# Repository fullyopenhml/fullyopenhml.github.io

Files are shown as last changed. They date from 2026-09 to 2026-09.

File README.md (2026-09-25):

# Fully Open Humanoid

Three things in one site, at https://fullyopenhml.github.io/:

- **Catalog** (`catalog.html`): open-source humanoids, bipeds and hands scored on nine
  openness criteria, with cost, size, DOF, actuators, licences and sources.
- **Builder** (`builder.html`): mix legs, torso, arms, hands and head across projects;
  get a compatibility checklist (verified / unverified / adapter needed), a merged BOM
  with prices and a sourcing list.
- **Our reference design**: a 23-DOF, 1.1 m humanoid on RobStride actuators and
  3D-printed structure, keeping the joint layout of [Duke Humanoid V2](https://generalroboticslab.github.io/Duke_Humanoid_V2_OpenSource/)
  and the no-machining build of [Berkeley Humanoid Lite](https://berkeley-humanoid-lite.gitbook.io/docs).
  About $5.8k in parts, zero CNC parts, unbuilt.

## Layout

| Path | What |
| --- | --- |
| `index.html`, `design.html`, `viewer.html`, `bom.html`, `printing.html`, `assembly.html`, `electrical.html`, `bringup.html`, `software.html`, `reference.html` | The site: plain HTML, no build step |
| `catalog.html`, `builder.html`, `assets/js/builder.js` | The catalog and the mix-and-match builder, both rendered from `assets/data/catalog.json` |
| `tools/catalog_src.py` | **The catalog.** One dictionary per robot with sources, criteria, families, static modules; `tools/build_catalog.py` merges it with the computed modules of our design and Duke V2 |
| `tools/build_geometry.py` | Builds the builder's 3D modules: one decimated GLB per module in `assets/geom/` plus anchors in `assets/data/module_geom.json`, from our primitives, Duke V2's viewer GLB and the URDFs of BHL, LeRobot Humanoid, Open Duck Mini and MEVITA (meshes cached in `tools/.cache/`) |
| `assets/js/mix-viewer.js` | The builder's live 3D view (three.js), composes the selected modules by matching anchors |
| `tools/build_data.py` | **The model.** Every part, joint, price. Writes the three files below |
| `assets/data/robot.json` | Links, joints, part occurrences as primitive solids, catalogue, poses, specs |
| `assets/data/bom.json` | Bill of materials by section and tier |
| `assets/model/foh_v0_2.urdf` | Robot description with masses and inertias |
| `assets/print/` | One STL per printed part plus a zip; `assets/data/print_files.json` is the manifest |
| `tools/build_parts.py` | STL generator (CSG with manifold3d); `tools/check_collisions.py` is the self-collision audit |
| `assets/js/robot-viewer.js` | The CAD-style viewer (three.js from a CDN), builds the robot from `robot.json` |
| `assets/js/site.js`, `assets/css/site.css` | Shared behaviour and styles |
| `Duke_Humanoid_V2_OpenSource/`, `berkeley-humanoid-lite/` | The two parent projects, kept for reference |

## Working on it

```bash
python3 tools/build_data.py          # regenerate robot.json, bom.json and the URDF after any change
python3 tools/check_collisions.py --poses --sweep   # self-collision audit
python3 tools/build_catalog.py       # regenerate catalog.json after editing tools/catalog_src.py
uv pip install --python tools/.venv/bin/python open3d DracoPy pycollada
tools/.venv/bin/python tools/build_geometry.py     # regenerate the builder's module GLBs and anchors
uv venv tools/.venv --python 3.12 && uv pip install --python tools/.venv/bin/python manifold3d trimesh numpy
tools/.venv/bin/python tools/build_parts.py         # regenerate the STLs and the manifest
python3 -m http.server 8000          # then open http://localhost:8000/
```

Change a dimension, a part or a price in `tools/build_data.py`; every page, the
viewer and the URDF follow. Never edit the generated files by hand.

## Status

v0.2 is a design release: kinematics, part list, cost model, wiring, URDF and every printed part as STL.
Nothing has been built yet. The roadmap on the home page lists what each
version adds and which numbers turn from estimates into measurements.

## Licence

Code is MIT (`LICENSE`). Hardware design files and documentation are CC BY 4.0.
See the [reference page](https://fullyopenhml.github.io/reference.html#license).

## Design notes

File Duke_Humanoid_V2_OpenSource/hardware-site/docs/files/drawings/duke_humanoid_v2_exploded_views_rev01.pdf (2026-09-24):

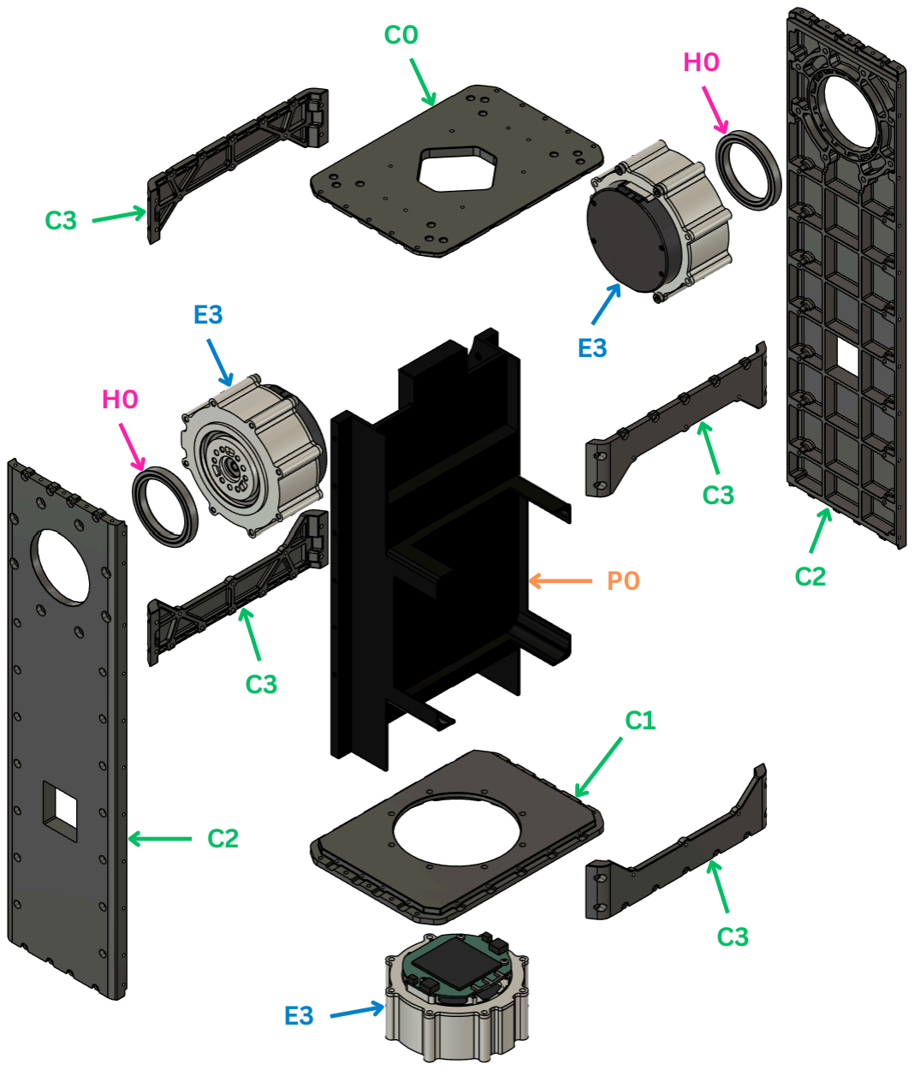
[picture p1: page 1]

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
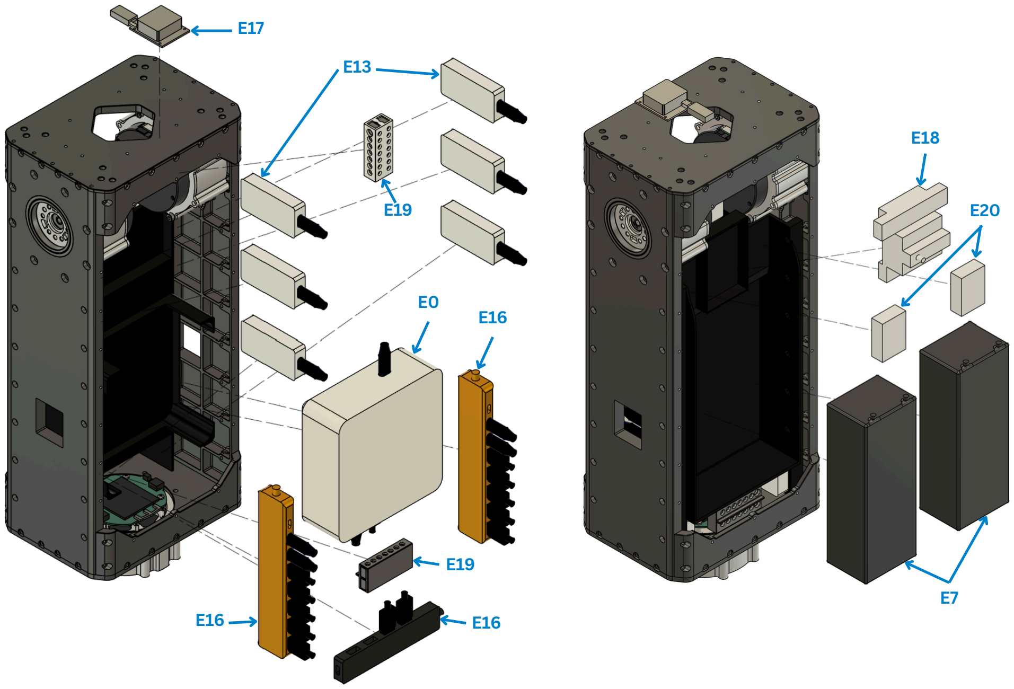
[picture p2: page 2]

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
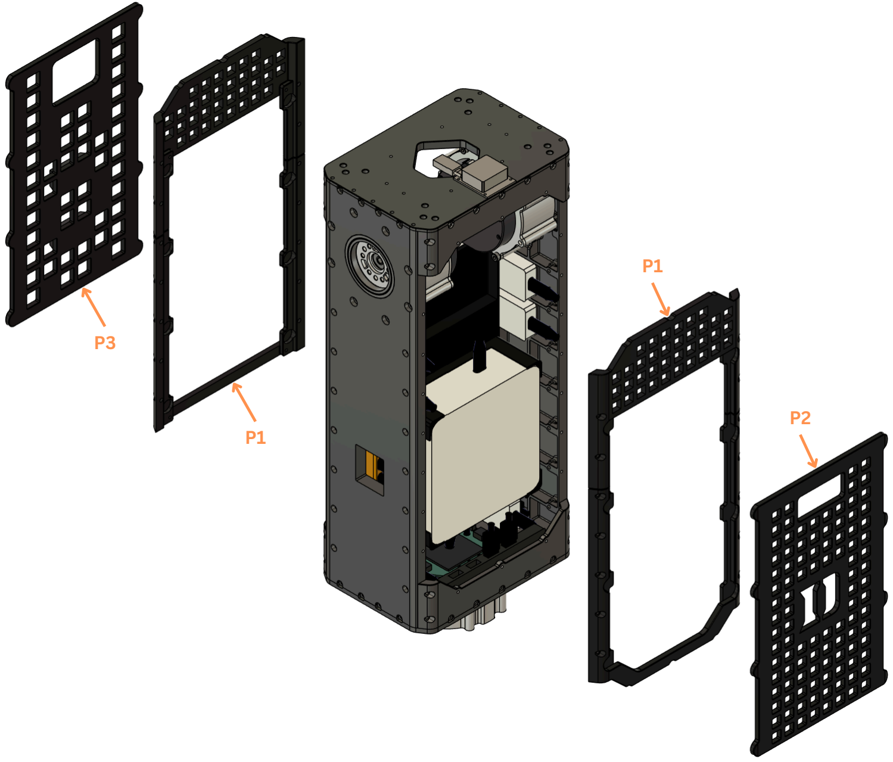
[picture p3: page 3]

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
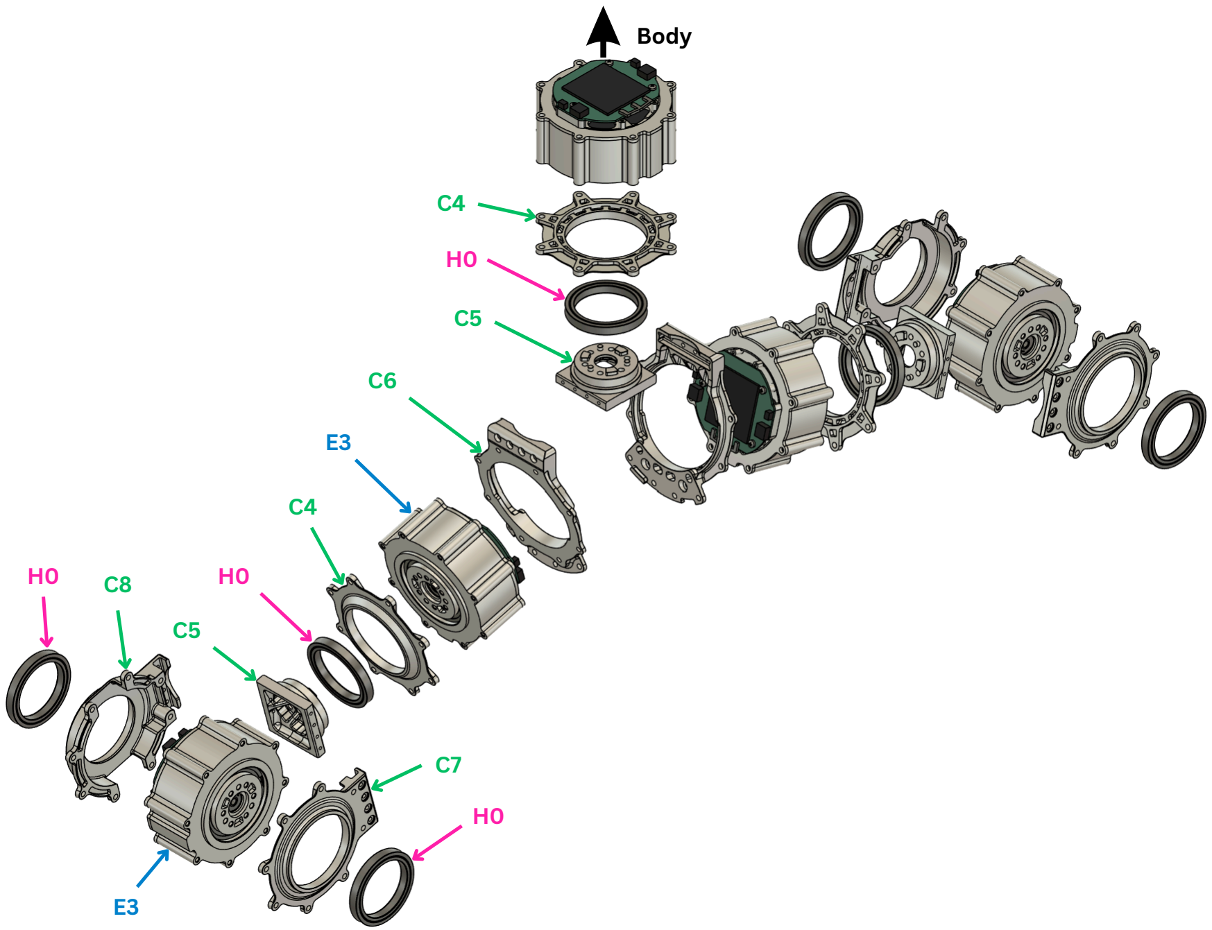
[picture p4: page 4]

Body

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
H C8 0

H0

H0

H0

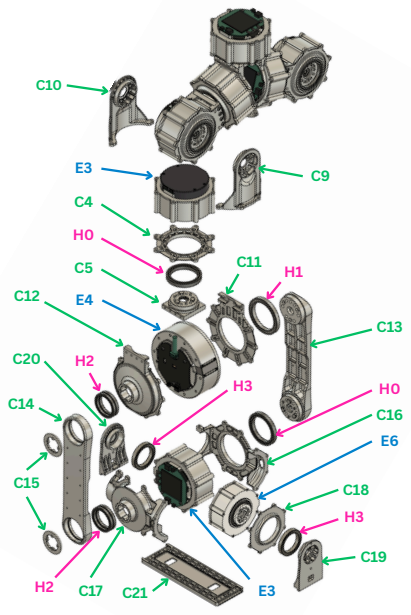
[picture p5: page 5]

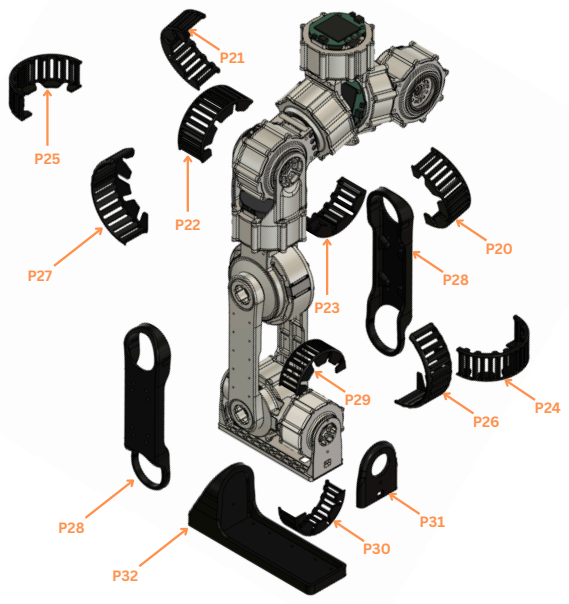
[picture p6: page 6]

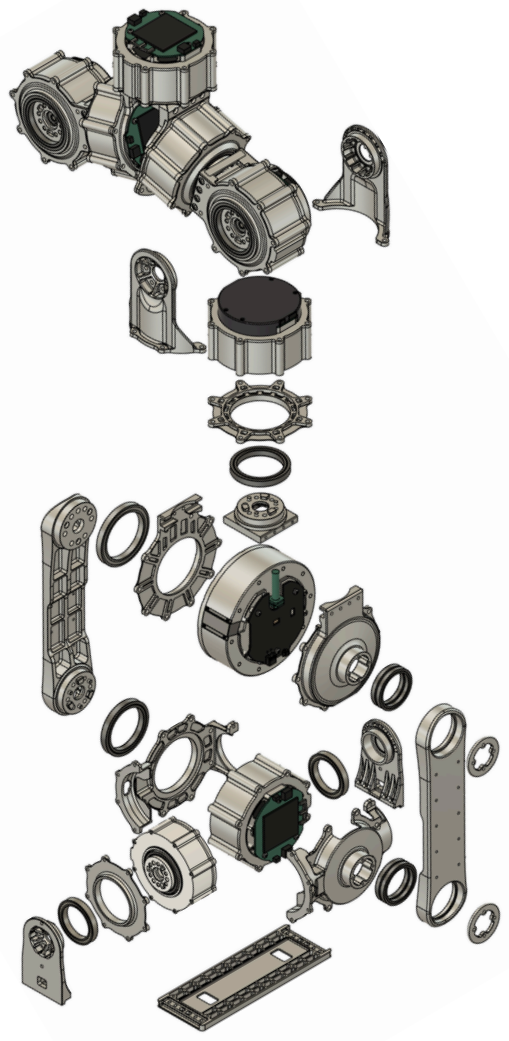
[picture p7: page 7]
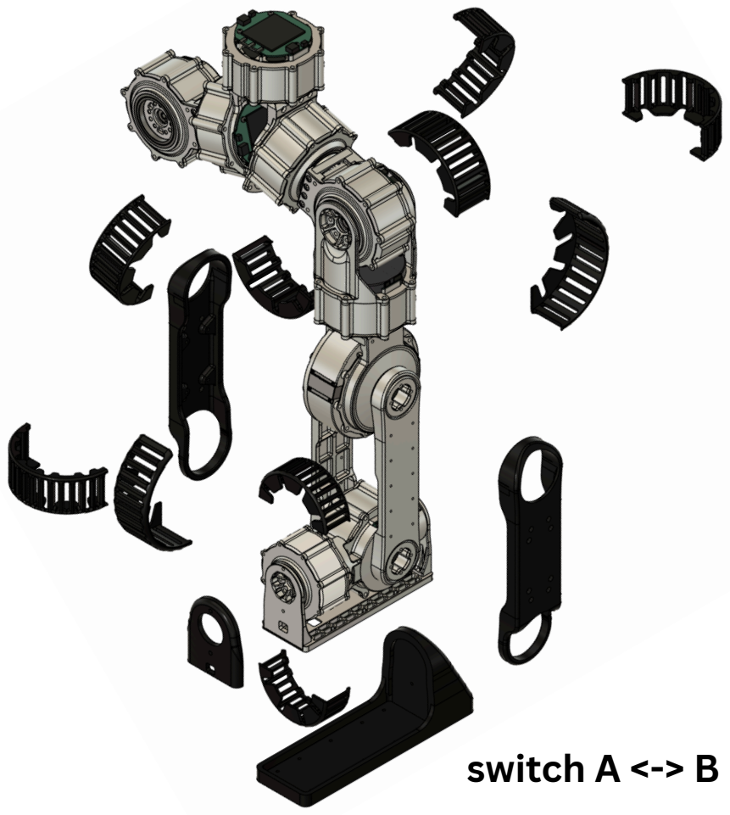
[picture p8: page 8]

# switch A <-> B

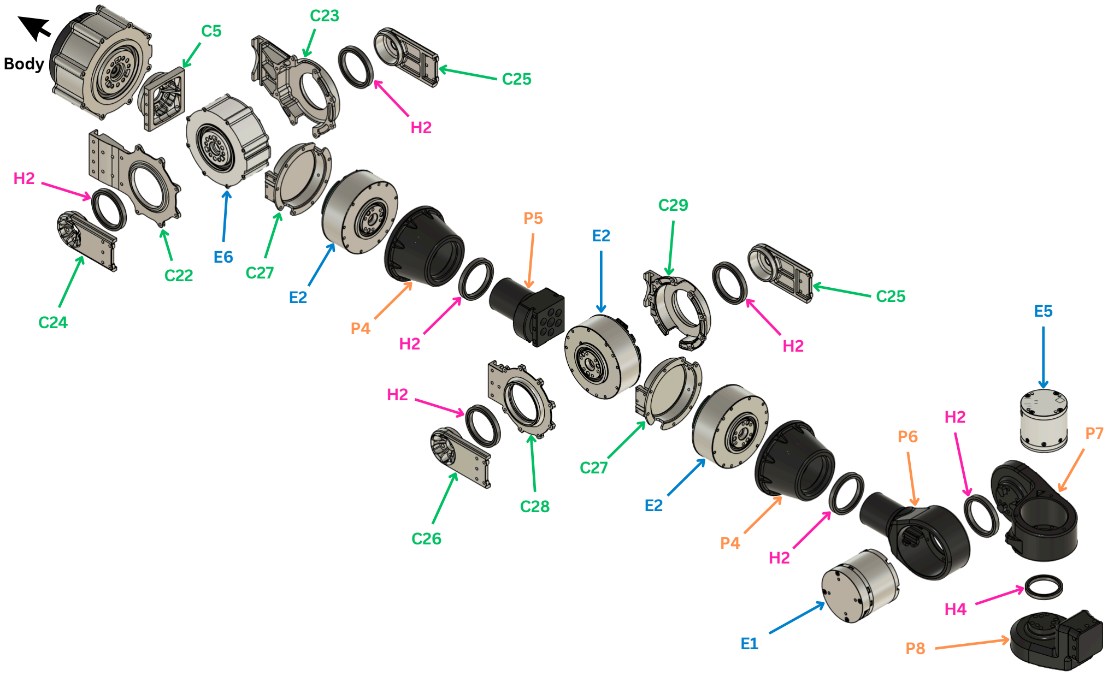
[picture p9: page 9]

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
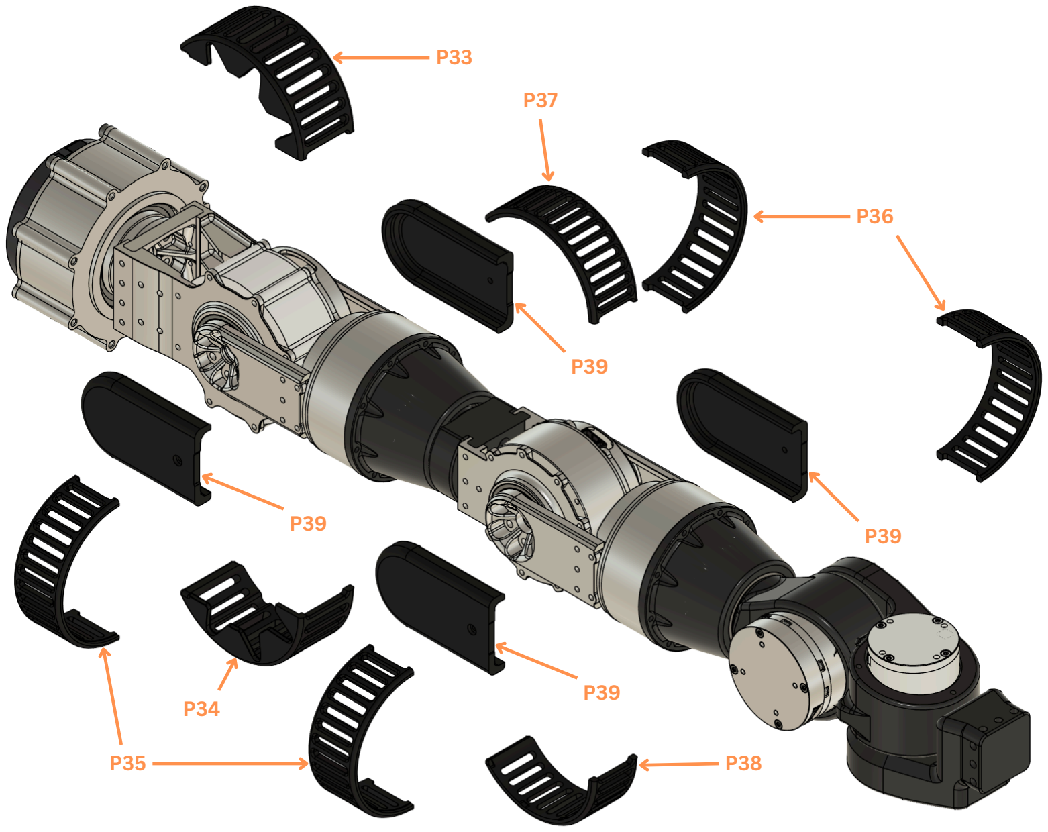
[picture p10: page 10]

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
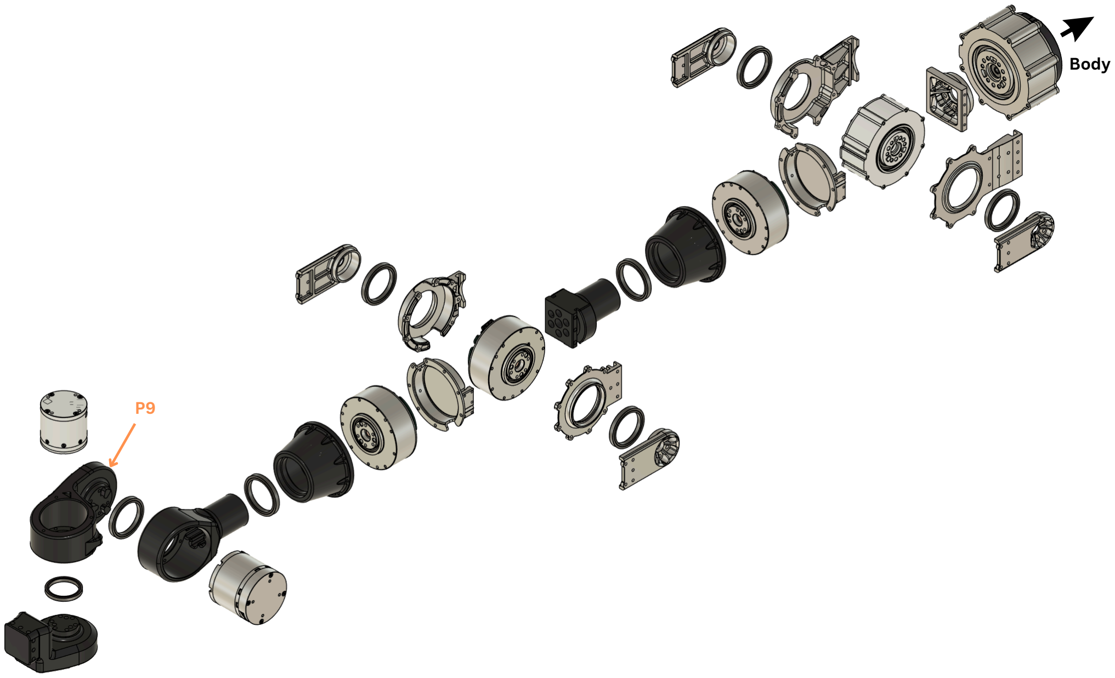
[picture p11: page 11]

B

o

d

y

P

9

# switch A <-> B

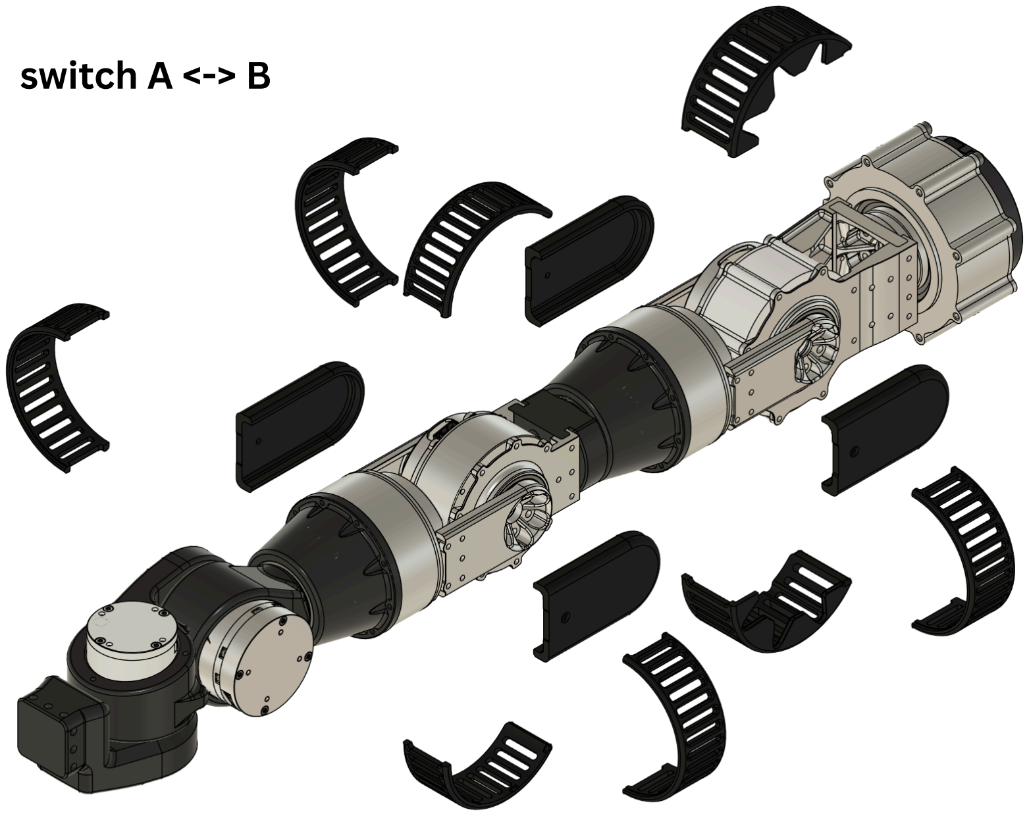
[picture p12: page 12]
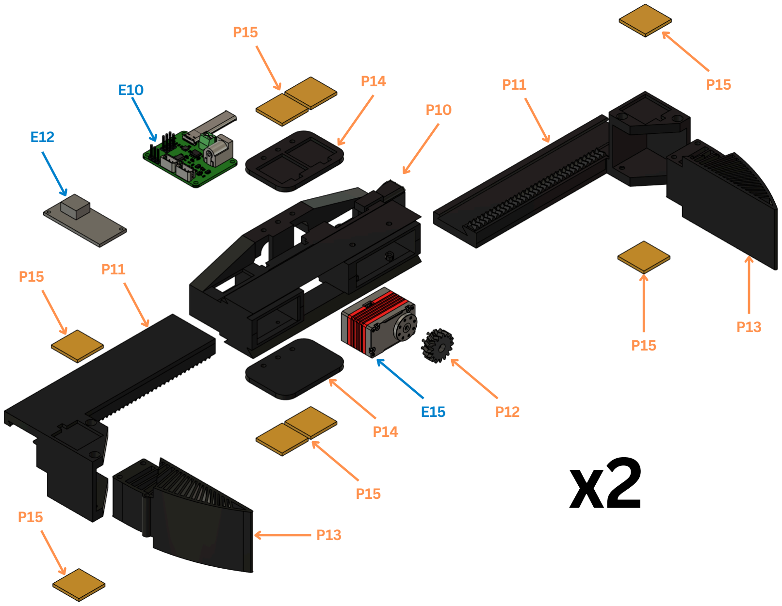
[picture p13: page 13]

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
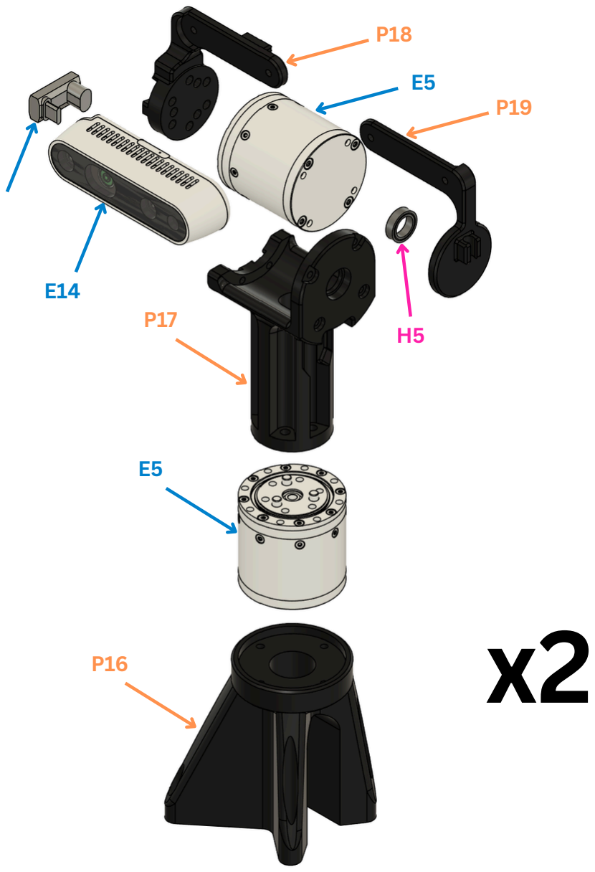
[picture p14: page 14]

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
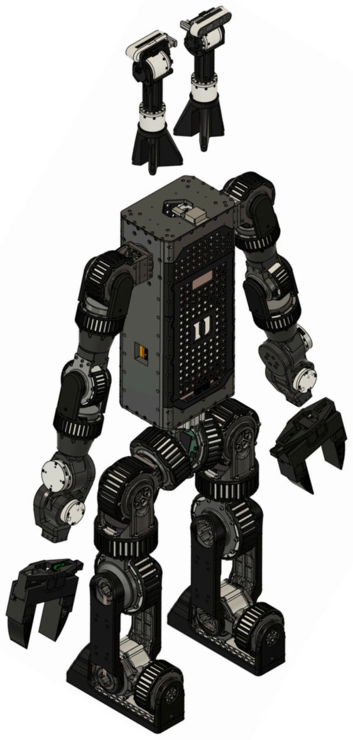
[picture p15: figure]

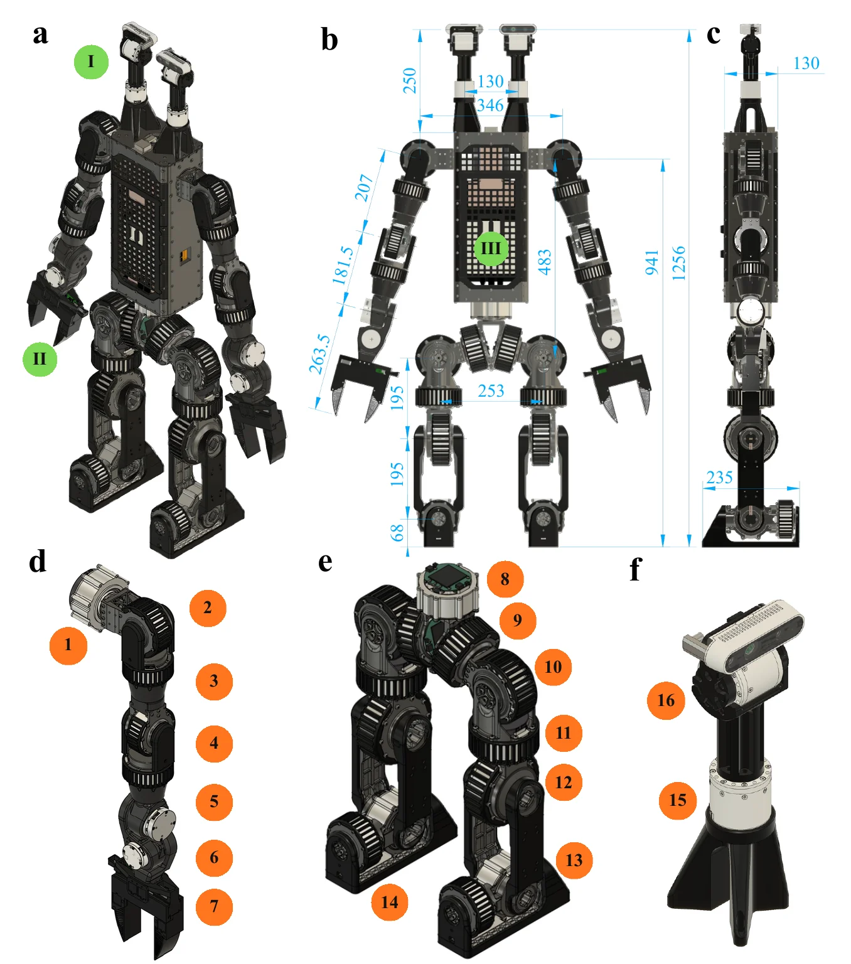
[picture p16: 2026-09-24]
Duke_Humanoid_V2_OpenSource/hardware-site/docs/assets/images/hardware.webp

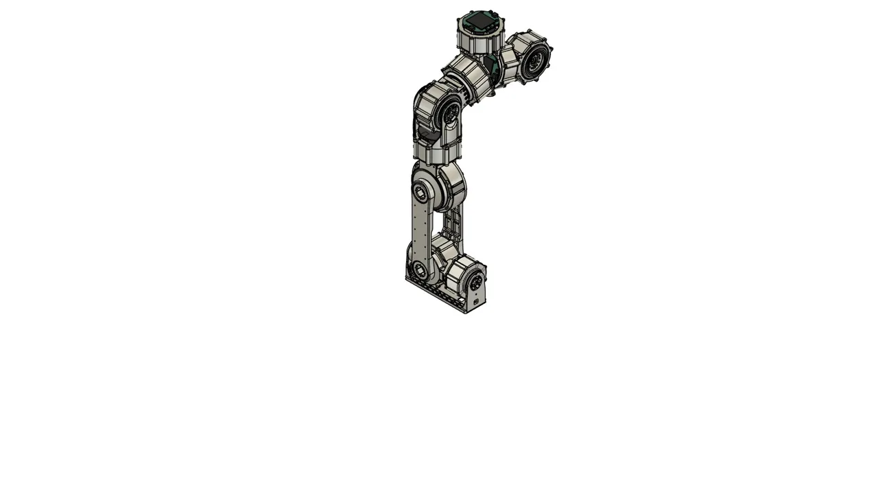
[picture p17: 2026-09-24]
Duke_Humanoid_V2_OpenSource/hardware-site/docs/assets/exploded/leg-poster.webp

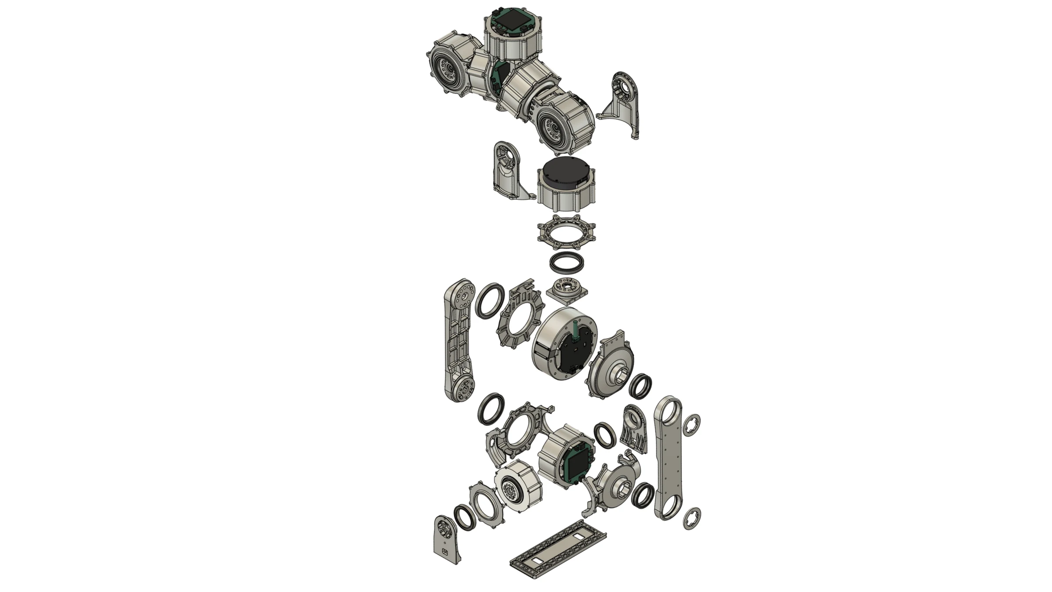
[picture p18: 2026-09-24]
Duke_Humanoid_V2_OpenSource/hardware-site/docs/assets/exploded/team/07-leg-unlabelled.webp

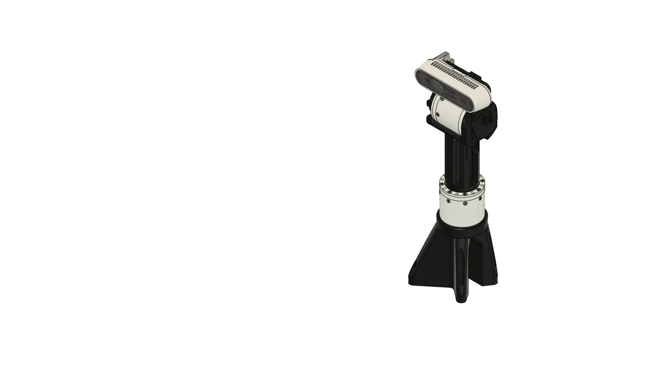
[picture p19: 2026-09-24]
Duke_Humanoid_V2_OpenSource/hardware-site/docs/assets/exploded/twincities-poster.webp

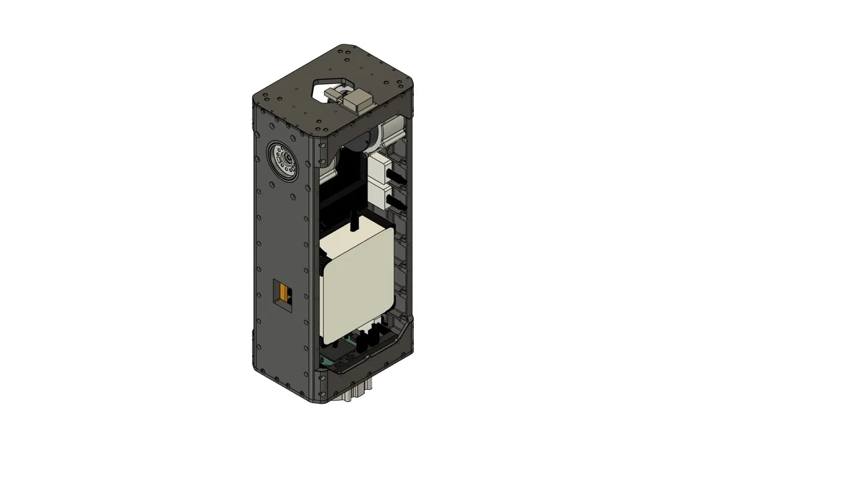
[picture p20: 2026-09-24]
Duke_Humanoid_V2_OpenSource/hardware-site/docs/assets/exploded/body-front-poster.webp

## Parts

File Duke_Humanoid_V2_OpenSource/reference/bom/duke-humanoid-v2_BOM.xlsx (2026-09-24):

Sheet: Sheet1
 | ITEM | LINK (shortened if possible) | UNIT COST | QUANTITY | TOTAL
ELECTRONICS | MINISFORUM X1-470 Mini PC | amazon.com/MINISFORUM-Desktop-Computer-HDMI2-1-Graphics/dp/B0GM43XCGT | $1295.00 | 1 | $1295.00
 | Robstride 00 QDD Actuator | https://www.robstride.com/products/robStride00 | $125 | 2 | $250.00
 | Robstride 02 QDD Actuator | https://www.robstride.com/products/robStride02 | $145 | 6 | $870.00
 | Robstride 03 QDD Actuator | https://www.robstride.com/products/robStride03 | $225 | 11 | $2475.00
 | Robstride 04 QDD Actuator | https://www.robstride.com/products/robStride04 | $255 | 2 | $510.00
 | Robstride 05 QDD Actuator | https://www.robstride.com/products/robStride05 | $110 | 6 | $660.00
 | Robstride 06 QDD Actuator | https://www.robstride.com/products/robStride06 | $210 | 4 | $840.00
 | Zeee 6S Lipo Battery 10000mAh 22.2V x2 | https://www.amazon.com/dp/B0BHQX8XQX?lv=shuf&channelId=500&plpRedirect=mhFallback | $306.00 | 1 | $306.00
 | TVS DIODE 53VWM 85VC | https://www.digikey.com/en/products/detail/microchip-technology/M1-5KE62CA/4349574 | $3.56 | 10 | $35.60
 | Belkin USB A to USB C Cable 2-Pack, 6.6ft | https://www.amazon.com/Belkin-USB-Cable-2-Pack-6-6ft/dp/B0F63XNWN3?th=1 | $14.99 | 2 | $29.98
 | Serial Bus Servo Driver Board for ST/SC Series Serial Bus Servos | https://www.waveshare.com/product/robotics/drivers-sensors/drivers/bus-servo-adapter-a.htm | $4.99 | 2 | $9.98
 | DC 20V-60V to 12V Encased Buck Converter | https://www.amazon.com/gp/product/B0G2SV9PFY?th=1 | $18.99 | 1 | $18.99
 | 48V to 12V Buck Converter | https://www.aliexpress.us/item/3256809688561615.html?spm=a2g0o.detail.0.0.4fd9AhcQAhcQuZ | $2.70 | 2 | $5.40
 | CANable PRO V2.0 USBCAN Controller | https://www.amazon.com/Macrobase-PRO-V2-0-Controller-transceiver/dp/B0GJSRZLBV/ | $20.80 | 6 | $124.80
 | RealSense Depth Camera D436 | https://store.realsenseai.com/buy-intel-realsense-depth-camera-d436.html | $354 | 2 | $708.00
 | Feetech HL-3915-C001 12V 14.2Kg Servo | https://aifitlab.com/products/feetech-hl-3915-servo-motor?variant=44326557417608 | $50 | 2 | $100.00
 | Vention USB Hub | https://www.amazon.com/VENTION-Splitter-Expander-Chromebook-Surface/dp/B0D2XWJ99H | $12.99 | 3 | $38.97
 | IMU | https://www.robotshop.com/products/syd-dynamics-transducerm-tm171-9-axis-ahrs-w-dual-port-communication | $57 | 1 | $57.00
HARDWARE | example: fasteners, nuts |  |  |  | $0.00
 | 5PCS Amass XT30(2+2). select Color (fist option): XT30U(2 2)-F | https://www.aliexpress.us/item/3256807585110718.html | $5.00 | 4 | $20.00
 | Frienda 30 Pairs XT30 Connectors Male and Female Connectors Plugs Set | https://www.amazon.com/Connectors-Female-Pieces-Shrink-Battery/dp/B0BB2XF5SQ?th=1 | $14.99 | 1 | $14.99
 | Alex Tech 25ft - 1/4 inch Cord Protector Wire Loom Tubing Cable Sleeve | https://www.amazon.com/Alex-Tech-10ft-Protector-Sleeving/dp/B07FW86XV6/?th=1 | $13.99 | 1 | $13.99
 | Alex Tech 25ft - 3/8 inch Cord Protector Wire Loom Tubing Cable Sleeve | https://www.amazon.com/Alex-Tech-25ft-Protector-Sleeving/dp/B07FW4M7Z8/?th=1 | $15.98 | 1 | $15.98
 | Duttek Short USB C Extension Cable 40Gbps | https://www.amazon.com/dp/B0CWGW3LTJ?th=1 | $9.76 | 2 | $19.52
 | USB A to USB C 3.1 Gen 2 Cable | https://www.amazon.com/Transfer-Charging-Samsung-SanDisk-Portable/dp/B09H2LLXPN?th=1 | $9.99 | 6 | $59.94
 | 1ft Short USB-C Cable with Right-Angle Plug | https://www.amazon.com/Afterplug-Right-Angle-Charging-Ultra-Flexible-Silicone/dp/B0G2LVGZ39 | $12.99 | 1 | $12.99
MATERIALS | CNC Leg Parts | TODO: BREAK INTO INDIVIDUAL CNC PARTS
 | CNC Arm Parts
 | CNC Body Parts
 | TPU
 | PLA
 | Nylon Powder for SLS
 |  |  |  | TOTAL CNC | 6389.86
 |  |  |  | GRAND TOTAL | $14881.99

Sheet: Sheet2
CNC_leg18_x2_foot_plate | 107.52 | 2pcs | 2076.98
CNC_leg17_x2_ankle_roll_support_shaft | 69.2 | 2 | 1374.19
CNC_leg05_x2_hip_roll_back_bearing_retainer | 136.04 | 2 | $1317.87
CNC_leg03_x5_RS03_shaft_bearing_retainer | 246.7 | 5 | $1620.82
CNC_leg06_x2_hip_roll_output_shaft | 119.92 | 2 | 6389.86
CNC_leg11_x2_knee_support_shank | 100.1 | 2
CNC_leg10_x2_knee_output_shank | 226.58 | 2
CNC_leg15_x2_RS06_shaft_bearing_retainer | 75.62 | 2
CNC_leg13_x2_ankle_pitch_front | 157.64 | 2
CNC_leg04_x2_hip_roll_front_bearing_retainer | 97.18 | 2
CNC_leg07_x2_hip_roll_support_shaft | 114.86 | 2
CNC_leg08_x2_knee_front_bearing_retainer | 109.62 | 2
CNC_leg16_x2_ankle_roll_output_shaft | 78.8 | 2
CNC_leg01_x2_hip_center_back | 163.18 | 2
CNC_leg02_x7_RS03_shaft_coupler | 274.02 | 6
CNC_arm13_x2_RS05_shaft_coupler | 109.8 | 3
CNC_leg14_x2_ankle_pitch_back | 191.7 | 2
CNC_leg09_x2_knee_motor_back_cover | 162.7 | 2
CNC_arm06_x4_RS02_shaft_coupler | $146.76 | 4
CNC_arm04_x4_shoulder_roll_support_shaft | $115.12 | 4
CNC_body03_x1_top_plate | $64.53 | 1
CNC_arm05_x4_RS02_shaft_bearing | $123.08 | 4
CNC_arm03_x2_shoulder_roll_output_shaft | $63.44 | 2
CNC_body02_x2_side_plate | $218.28 | 2
CNC_leg02_x7_RS03_shaft_coupler | $100.26 | 2
CNC_body04_x4_front_plate | $188.32 | 4
CNC_arm11_x2_wrist_roll | $239.58 | 2
CNC_arm10_x4_r03_back_cover | $217.00 | 4
CNC_arm09_x2_elbow_output_shaft | $62.84 | 2
CNC_body01_x1_bottom_plate | $64.03 | 1
CNC_arm01_x2_shoulder_roll_front_bearing | $93.38 | 2
CNC_arm08_x2_elbow_back_bearing | $131.30 | 2
CNC_arm12_x2_wrist_pitch | $192.52 | 2
CNC_arm07_x2_elbow_front_bearing | $115.88 | 2
CNC_arm02_x2_shoulder_roll_back_bearing | $198.48 | 2
CNC_leg12_x4_lower_leg_bearing | $82.50 | 5
02_hip_0_m04_back_bracket_x2 | $159.94 | 2
B6_single_leg_tester_plate | $101.38 | 1
08_hip_1_back_shaft_x2 | $37.93 | 1
B5_body_shelf | $93.71 | 1
13_knee_front_shaft_x2 | $60.82 | 1
17_ankle_0_back_cover_x2 | $76.78 | 1
15_ankle_cap_x4 | $38.64 | 2
B1_body_base_plate | $95.01 | 1
05_hip_1_front_bracket_x2 | $49.62 | 1
18_ankle_1_back_retainer_x2 | $23.37 | 1
22_foot_plate_x2 | $22.48 | 1
12_knee_m04_back_cover_x2 | $72.92 | 1
21_ankle_1_front_shaft_x4 | $75.00 | 2
04_hip_1_m04_shaft_x2 | $41.28 | 1
06_hip_1_back_bracket_x2 | $70.42 | 1
09_hip_2_back_cover_x2 | $63.00 | 1
10_m03_front_retainer_x2 | $40.06 | 1
01_m03_shaft_x3 | $92.77 | 2
16_ankle_0_front_retainer_x2 | $53.34 | 1
03_hip_1_m04_front_retainer_x2 | $54.29 | 1
B3_body_side_plate_x2 | $198.11 | 2
B2_body_top_plate | $126.84 | 1
14_knee_back_shaft_x2 | $59.48 | 1
19_ankle_1_m02_back_cover_x2 | $49.79 | 1
11_knee_m04_front_retainer_x2 | $48.44 | 1
07_hip_1_front_shaft_x2 | $38.04 | 1
20_ankle_1_front_retainer_x2 | $38.68 | 1

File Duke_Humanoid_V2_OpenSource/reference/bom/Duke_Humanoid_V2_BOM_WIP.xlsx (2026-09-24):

Category | # | Item | Link | Unit Cost | Quantity | Total Cost | link | weight (check urdf) | price per unit weight
Electronics | E0 | MINISFORUM X1-470 Mini PC | https://www.amazon.com/MINISFORUM-X1-Pro-470-Quad-Display-Bluetooth/dp/B0GL2PPG67 | $1295.00 | 1 | $1295.00 | https://www.amazon.com/MINISFORUM-X1-Pro-470-Quad-Display-Bluetooth/dp/B0GL2PPG67
Electronics | E1 | Robstride 00 QDD Actuator | https://www.amazon.com/RobStride-14N-m-Integrated-Actuator-Module/dp/B0GS4XFK7Z/ | $125.00 | 2 | $250.00 | https://www.amazon.com/RobStride-14N-m-Integrated-Actuator-Module/dp/B0GS4XFK7Z/
Electronics | E2 | Robstride 02 QDD Actuator | https://www.amazon.com/RobStride-Integrated-Actuator-Module-Encoders/dp/B0GS5945VP | $145.00 | 6 | $870.00 | https://www.amazon.com/RobStride-Integrated-Actuator-Module-Encoders/dp/B0GS5945VP
Electronics | E3 | Robstride 03 QDD Actuator | https://www.amazon.com/RobStride-60N-m-Integrated-Actuator-Module/dp/B0GY8PJ1MF | $225.00 | 11 | $2475.00 | https://www.amazon.com/RobStride-60N-m-Integrated-Actuator-Module/dp/B0GY8PJ1MF
Electronics | E4 | Robstride 04 QDD Actuator | https://www.amazon.com/RobStride-120N-m-Integrated-Actuator-Module/dp/B0GY8T32L9 | $255.00 | 2 | $510.00 | https://www.amazon.com/RobStride-120N-m-Integrated-Actuator-Module/dp/B0GY8T32L9
Electronics | E5 | Robstride 05 QDD Actuator | https://aifitlab.com/products/robstride-05-motor | $110.00 | 6 | $660.00 | https://aifitlab.com/products/robstride-05-motor
Electronics | E6 | Robstride 06 QDD Actuator | https://aifitlab.com/products/robstride-06-motor | $210.00 | 2 | $420.00 | https://aifitlab.com/products/robstride-06-motor
Electronics | E7 | Zeee 6S Lipo Battery 10000mAh 22.2V x2 | https://zeeebattery.com/products/zeee-6s-lipo-battery-10000mah-22-2v-120c-ec5 | $367.00 | 1 | $367.00 | https://zeeebattery.com/products/zeee-6s-lipo-battery-10000mah-22-2v-120c-ec5
Electronics | E8 | TVS DIODE 53VWM 85VC | https://www.digikey.com/en/products/detail/microchip-technology/M1-5KE62CA/4349574 | $3.56 | 10 | $35.60 | https://www.digikey.com/en/products/detail/microchip-technology/M1-5KE62CA/4349574
Electronics | E9 | Belkin USB A to USB C Cable 2-Pack, 6.6ft | https://www.amazon.com/Belkin-USB-Cable-2-Pack-6-6ft/dp/B0F63XNWN3?th=1 | $14.99 | 2 | $29.98 | https://www.amazon.com/Belkin-USB-Cable-2-Pack-6-6ft/dp/B0F63XNWN3?th=1
Electronics | E10 | Serial Bus Servo Driver Board for ST/SC Series Serial Bus Servos | https://www.waveshare.com/product/robotics/drivers-sensors/drivers/bus-servo-adapter-a.htm | $4.99 | 2 | $9.98 | https://www.waveshare.com/product/robotics/drivers-sensors/drivers/bus-servo-adapter-a.htm
Electronics | E11 | DC 20V-60V to 12V Encased Buck Converter | https://www.amazon.com/gp/product/B0G2SV9PFY?th=1 | $18.99 | 1 | $18.99 | https://www.amazon.com/gp/product/B0G2SV9PFY?th=1
Electronics | E12 | 48V to 12V Buck Converter | https://www.aliexpress.us/item/3256809688561615.html?spm=a2g0o.detail.0.0.4fd9AhcQAhcQuZ | $2.70 | 2 | $5.40 | https://www.aliexpress.us/item/3256809688561615.html?spm=a2g0o.detail.0.0.4fd9AhcQAhcQuZ
Electronics | E13 | CANable PRO V2.0 USBCAN Controller | https://www.amazon.com/Macrobase-PRO-V2-0-Controller-transceiver/dp/B0GJSRZLBV/ | $20.80 | 6 | $124.80 | https://www.amazon.com/Macrobase-PRO-V2-0-Controller-transceiver/dp/B0GJSRZLBV/
Electronics | E14 | RealSense Depth Camera D436 | https://store.realsenseai.com/buy-intel-realsense-depth-camera-d436.html | $354.00 | 2 | $708.00 | https://store.realsenseai.com/buy-intel-realsense-depth-camera-d436.html
Electronics | E15 | Feetech HL-3915-C001 12V 14.2Kg Servo | https://aifitlab.com/products/feetech-hl-3915-servo-motor?variant=44326557417608 | $50.00 | 2 | $100.00 | https://aifitlab.com/products/feetech-hl-3915-servo-motor?variant=44326557417608
Electronics | E16 | Vention USB Hub | https://www.amazon.com/VENTION-Splitter-Expander-Chromebook-Surface/dp/B0D2XWJ99H | $12.99 | 3 | $38.97 | https://www.amazon.com/VENTION-Splitter-Expander-Chromebook-Surface/dp/B0D2XWJ99H
Electronics | E17 | IMU | https://www.robotshop.com/products/syd-dynamics-transducerm-tm171-9-axis-ahrs-w-dual-port-communication | $57.00 | 1 | $57.00 | https://www.robotshop.com/products/syd-dynamics-transducerm-tm171-9-axis-ahrs-w-dual-port-communication
Electronics | E18 | TTocas Surge Protector | https://www.amazon.com/stores/TTocas/page/CAFB5466-628D-45E8-B728-7DB6F3AD931F | $22.99 | 1 | $22.99 | https://www.amazon.com/stores/TTocas/page/CAFB5466-628D-45E8-B728-7DB6F3AD931F
Electronics | E19 | Power Distribution Block Terminals | https://www.aliexpress.us/item/3256808232612352.html | $0.53 | 4 | $2.12 | https://www.aliexpress.us/item/3256808232612352.html
Electronics | E20 | Voltage Sensor for LiPo | https://epowerhobby.com/product/lipo-voltage-checker-1-8s-with-case/ | $14.50 | 2 | $29.00 | https://epowerhobby.com/product/lipo-voltage-checker-1-8s-with-case/
CNC | C0 | Body Plate - Top |  | $64.53 | 1 | $64.53
CNC | C1 | Body Plate - Bottom |  | $64.03 | 1 | $64.03
CNC | C2 | Body Plate - Side |  | $109.14 | 2 | $218.28
CNC | C3 | Body Plate - Front/Back |  | $47.08 | 4 | $188.32
CNC | C4 | Robstride 03 Bearing Retainer |  | $49.34 | 5 | $246.70
CNC | C5 | Robstride 03 Output Shaft |  | $46.78 | 7 | $327.50
CNC | C6 | Hip 1 Motor Bracket |  | $81.59 | 2 | $163.18
CNC | C7 | Hip 2 Motor Bracket |  | $48.59 | 2 | $97.18
CNC | C8 | Hip 2 Bearing Retainer |  | $68.02 | 2 | $136.04
CNC | C9 | Hip 3 Output Shaft |  | $59.96 | 2 | $119.92
CNC | C10 | Hip 3 Supporting Shaft |  | $57.43 | 2 | $114.86
CNC | C11 | Knee Motor Bracket |  | $54.81 | 2 | $109.62
CNC | C12 | Knee Bearing Retainer |  | $81.35 | 2 | $162.70
CNC | C13 | Shank Shaft |  | $113.29 | 2 | $226.58
CNC | C14 | Shank Support |  | $50.05 | 2 | $100.10
CNC | C15 | Shank Joint Cap |  | $16.50 | 4 | $66.00
CNC | C16 | Ankle Motor Bracket |  | $78.82 | 2 | $157.64
CNC | C17 | Ankle Bearing Retainer |  | $95.85 | 2 | $191.70
CNC | C18 | Robstride 06 Bearing Retainer |  | $37.81 | 2 | $75.62
CNC | C19 | Foot Shaft |  | $39.40 | 2 | $78.80
CNC | C20 | Foot Support |  | $34.60 | 2 | $69.20
CNC | C21 | Foot |  | $53.76 | 2 | $107.52
CNC | C22 | Shoulder Motor Bracket |  | $46.69 | 2 | $93.38
CNC | C23 | Shoulder Bearing Retainer |  | $99.24 | 2 | $198.48
CNC | C24 | Shoulder Shaft |  | $31.72 | 2 | $63.44
CNC | C25 | Shoulder/Elbow Support |  | $57.56 | 4 | $230.24
CNC | C26 | Elbow Shaft |  | $31.42 | 2 | $62.84
CNC | C27 | Shoulder/Elbow Coupler |  | $54.25 | 4 | $217.00
CNC | C28 | Elbow Motor Bracket |  | $57.94 | 2 | $115.88
CNC | C29 | Elbow Bearing Retainer |  | $65.65 | 2 | $131.30
3DP | P0 | PC Mount, PLA |  | $3.96 | 1 | $3.96 |  | 0.3175725 | 12.47 | 3.960129075
3DP | P1 | Body Cover, PLA |  | $0.92 | 2 | $1.84 |  | 0.073888034 | 12.47 | 0.921383784
3DP | P2 | Front Plate, PLA |  | $1.21 | 1 | $1.21 |  | 0.096876586 | 12.47 | 1.208051027
3DP | P3 | Back Plate, PLA |  | $1.42 | 1 | $1.42 |  | 0.113809991 | 12.47 | 1.419210588
3DP | P4 | Arm Shaft Cover, Nylon 12 |  | $7.06 | 4 | $28.22 |  | 0.070624732 | 99.9 | 7.055410727
3DP | P5 | Elbow Shaft Coupler, Nylon 12 |  | $6.45 | 2 | $12.91 |  | 0.064589607 | 99.9 | 6.452501739
3DP | P6 | Wrist Shaft, Nylon 12 |  | $7.20 | 2 | $14.41 |  | 0.072102192 | 99.9 | 7.203008981
3DP | P7 | Wrist Housing R, Nylon 12 |  | $13.78 | 1 | $13.78 |  | 0.137950732 | 99.9 | 13.78127813
3DP | P8 | Wrist Output, Nylon 12 |  | $13.01 | 2 | $26.02 |  | 0.130220812 | 99.9 | 13.00905912
3DP | P9 | Wrist Housing L, Nylon 12 |  | $13.78 | 1 | $13.78 |  | 0.137950732 | 99.9 | 13.78127813
3DP | P10 | Gripper Housing, PLA |  | $0.96 | 2 | $1.91 |  | 0.07666666 | 12.47 | 0.9560332502
3DP | P11 | Gripper Rack, PLA |  | $0.56 | 4 | $2.24 |  | 0.044855 | 12.47 | 0.55934185
3DP | P12 | Gear, Nylon 12 |  | $0.13 | 2 | $0.26 |  | 0.00129 | 99.9 | 0.128871
3DP | P13 | UMI Fingers, TPU |  | $0.42 | 4 | $1.69 |  | 0.03395 | 12.47 | 0.4233565
3DP | P14 | AprilTag Housing, PLA |  | $0.04 | 4 | $0.16 |  | 0.003264 | 12.47 | 0.04070208
3DP | P15 | AprilTags, PLA |  | $0.02 | 12 | $0.21 |  | 0.0014 | 12.47 | 0.017458
3DP | P16 | Gimbal Base, PLA |  | $0.65 | 2 | $1.30 |  | 0.05198 | 12.47 | 0.6481906
3DP | P17 | Gimbal Neck, PLA |  | $0.47 | 2 | $0.94 |  | 0.037643 | 12.47 | 0.46940821
3DP | P18 | Gimbal Shaft, PLA |  | $0.16 | 2 | $0.31 |  | 0.012475 | 12.47 | 0.15556325
3DP | P19 | Gimbal Support, PLA |  | $0.15 | 2 | $0.30 |  | 0.012103 | 12.47 | 0.15092441
3DP | P20 | Hip 1 Protection - A, TPU |  | $1.09 | 2 | $2.18 |  | 0.031094 | 34.99 | 1.08797906
3DP | P21 | Hip 1 Protection - B, TPU |  | $1.09 | 2 | $2.18 |  | 0.031094 | 34.99 | 1.08797906
3DP | P22 | Hip 2 Protection - A, TPU |  | $0.91 | 2 | $1.82 |  | 0.025962 | 34.99 | 0.90841038
3DP | P23 | Hip 2 Protection - B, TPU |  | $0.91 | 2 | $1.82 |  | 0.025962 | 34.99 | 0.90841038
3DP | P24 | Hip 3 Protection - A, TPU |  | $1.09 | 2 | $2.18 |  | 0.031094 | 34.99 | 1.08797906
3DP | P25 | Hip 3 Protection - B, TPU |  | $1.09 | 2 | $2.18 |  | 0.031094 | 34.99 | 1.08797906
3DP | P26 | Knee Protection - A, TPU |  | $0.92 | 2 | $1.83 |  | 0.026159 | 34.99 | 0.91530341
3DP | P27 | Knee Protection - B, TPU |  | $0.92 | 2 | $1.83 |  | 0.026159 | 34.99 | 0.91530341
3DP | P28 | Shank Protection, TPU |  | $1.56 | 4 | $6.26 |  | 0.044714 | 34.99 | 1.56454286
3DP | P29 | Foot Protection - Top, TPU |  | $0.58 | 2 | $1.17 |  | 0.016691 | 34.99 | 0.58401809
3DP | P30 | Foot Protection - Bot, TPU |  | $0.58 | 2 | $1.17 |  | 0.016691 | 34.99 | 0.58401809
3DP | P31 | Foot Protection - Front, TPU |  | $0.49 | 2 | $0.97 |  | 0.013896 | 34.99 | 0.48622104
3DP | P32 | Foot Protection - Sole, TPU |  | $4.14 | 2 | $8.28 |  | 0.118364 | 34.99 | 4.14155636
3DP | P33 | Shoulder 2 Protection - A, TPU |  | $0.44 | 2 | $0.87 |  | 0.012454 | 34.99 | 0.43576546
3DP | P34 | Shoulder 2 Protection - B, TPU |  | $0.44 | 2 | $0.87 |  | 0.012454 | 34.99 | 0.43576546
3DP | P35 | Arm Roll Protection - Front, TPU |  | $0.29 | 4 | $1.16 |  | 0.008313 | 34.99 | 0.29087187
3DP | P36 | Arm Roll Protection - Back, TPU |  | $0.29 | 4 | $1.16 |  | 0.008313 | 34.99 | 0.29087187
3DP | P37 | Elbow Protection - A, TPU |  | $0.21 | 2 | $0.43 |  | 0.006124 | 34.99 | 0.21427876
3DP | P38 | Elbow Protection - B, TPU |  | $0.21 | 2 | $0.43 |  | 0.006124 | 34.99 | 0.21427876
3DP | P39 | Arm Roll Shaft Protection, TPU |  | $0.27 | 8 | $2.13 |  | 0.007623 | 34.99 | 0.26672877
Hardware | H0 | 45x58x7 Ball Bearing | https://www.amazon.com/XIKE-6809-2RS-Bearings-45x58x7mm-Pre-Lubricated/dp/B09D2J9P82 | $3.00 | 13 | $39.00
Hardware | H1 | 50x65x7 Ball Bearing | https://www.amazon.com/uxcell-6810-2RS-Groove-Bearings-Double/dp/B082PYMQFL | $4.00 | 2 | $8.00
Hardware | H2 | 35x44x5 Ball Bearing | https://www.amazon.com/XIKE-6707-2RS-Bearings-35x44x5mm-Pre-Lubricated/dp/B09D2XN464/ | $3.00 | 18 | $54.00
Hardware | H3 | 35x47x7 6807-2RS Ball Bearing | https://www.amazon.com/XIKE-6807-2RS-Bearings-35x47x7mm-Pre-Lubricated/dp/B09D2ZHNPH/ | $4.00 | 4 | $16.00
Hardware | H4 | 30x37x4 6706-2RS Ball Bearing | https://www.amazon.com/XIKE-6706-2RS-Bearings-30x37x4mm-Pre-Lubricated/dp/B09D35XB19 | $2.00 | 2 | $4.00
Hardware | H5 | 10x15x4 Ball Bearing | https://www.amazon.com/uxcell-6700-2RS-Groove-Bearings-Double/dp/B082PR3DFZ | $1.00 | 2 | $2.00
Hardware | H6 | M3x10 Torx Button Head Screw | https://www.mcmaster.com/90991A114/ | $5.16 | 5 | $25.80
Hardware | H7 | M4x8 Torx Button Head Screw | https://www.mcmaster.com/90991A121/ | $7.20 | 1 | $7.20
Hardware | H8 | M4x10 Torx Button Head Screw | https://www.mcmaster.com/90942A118/ | $5.78 | 4 | $23.12
Calibration |  |  |  |  |  | $0.00
SUM |  |  |  | $12575.30 | 299 | $12575.30

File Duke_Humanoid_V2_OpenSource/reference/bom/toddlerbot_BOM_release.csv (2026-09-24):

Type | Item Description | Vendor Link | Alternative Link | Unit Price | QTY (2XC) | Total Price | QTY (2XM) | Total Price | Note
Assembed Kit | ToddlerBot 2.0 Fully Assembled | https://shop.wowrobo.com/products/toddlerbot-2-0-assembly-version | https://item.taobao.com/item.htm?ft=t&id=970730280172 | $4,299 | 1 | $4,299.00 |  |  | Buy your own Jetson Orin NX 16G ($955), WiFi ($27.85). and Battery (~$50)
Disclaimer | We are not affiliated with or endorse this company in any way. We have not tested or validated the product. Any such offerings are independent of our project.
Essentials (Highlighted are additional things to buy from 1.0 to 2.0)
Motors | DYNAMIXEL 2XC430-W250-T | DYNAMIXEL 2XC430-W250-T - ROBOTIS |  | $298.89 | 2 | $597.78 | 6 | $1,793.34
 | DYNAMIXEL 2XL430-W250-T | DYNAMIXEL 2XL430-W250-T - ROBOTIS |  | $149.39 | 6 | $896.34 | 0 | $0.00
 | DYNAMIXEL XC330-T288-T | DYNAMIXEL XC330-T288-T - ROBOTIS |  | $103.39 | 6 | $620.34 | 6 | $620.34
 | DYNAMIXEL XC430-T240BB-T | DYNAMIXEL XC430-T240BB-T - ROBOTIS |  | $137.89 | 4 | $551.56 | 4 | $551.56
 | DYNAMIXEL XM430-W210-T | DYNAMIXEL XM430-W210-T - ROBOTIS |  | $310.39 | 4 | $1,241.56 | 4 | $1,241.56
 | DYNAMIXEL XM430-W350-T | DYNAMIXEL XM430-W350-T - ROBOTIS |  | $310.39 | 0 | $0.00 | 4 | $1,241.56
 | DYNAMIXEL HN11-I101 Set | HN11-I101 Set - ROBOTIS |  | $8.05 | 10 | $80.50 | 8 | $64.40
 | DYNAMIXEL HN12-I101 Set | HN12-I101 Set - ROBOTIS |  | $20.47 | 4 | $81.88 | 6 | $122.82
 |  |  |  |  | $ of 2XC | $4,069.96 | $ of 2XC+ | $1,565.62
Parallel Gripper | DYNAMIXEL XC330-T288-T | DYNAMIXEL XC330-T288-T - ROBOTIS |  | $103.39 | 2 | $206.78
Computers | Jetson Orin NX 16G | NVIDIA® Jetson Orin™ NX 16GB AI Device - reComputer J4012 |  | $955.00 | 1 | $955.00 |  |  | Can replace with Jetson Orin Nano if budget is tight
 | M.2 CB375NF Wifi Card | Amazon.com: AW-CB375NF Wireless NIC, 2.4G/5GHz Dual-Band WiFi 5 Supports BLE, NGFF (M.2 A/E Key) Interface, for Jetson Xavier NX/Jetson Orin NX/Jetson Orin Nano : Electronics |  | $18.36 | 1 | $18.36
 | WiFi Antenna | Amazon.com: WiFi 6E Antenna IPX MHF4 Tri-Band 6GHz 5GHz 2.4GHz Internal Laptop Wi-Fi Antennas for AX200 AX210 1675X M.2 NGFF Card : Electronics |  | $9.49 | 1 | $9.49
Sensors | FIsheye Camera | Amazon.com: Arducam 1080P Low Light WDR Ultra Wide Angle USB Camera Module for Computer, 2MP CMOS IMX291 160 Degree Fisheye Mini UVC USB2.0 Webcam Board with Microphone, 3.3ft Cable for Windows Linux Mac OS : Electronics |  | $49.99 | 2 | $99.98
 | Phone Speaker | https://www.amazon.com/MMOBIEL-Replacement-iPhone-Plus-Screwdriver/dp/B079Z85L4N | Mmobiel Loud Speaker Compatible With Iphone Se 2022 Se 2020 | Desertcart Brunei | $5.99 | 1 | $5.99
 | Speaker Driver | Amazon.com: HiLetgo 3pcs M38 Wireless Bluetooth MP3 Audio Receiver Board BLT 4.2 mp3 Lossless decoder Bluetooth 4.2 Audio Receiver Board Wireless Stereo Sound Module : Electronics |  | $7.99 | 1 | $7.99
 | BNO085 IMU | Adafruit 9-DOF Orientation IMU Fusion Breakout - BNO085 (BNO080) [STEMMA QT / Qwiic] : ID 4754 : Adafruit Industries, Unique & fun DIY electronics and kits |  | $24.95 | 1 | $24.95
Hardware | M2*6 Pre-coated Screws | https://e.tb.cn/h.hFvWE8HfWc1pSka?tk=5rJm4l9H7bX |  | $0.01 | 200 | $1.80 |  |  | It is recommended to replace all positions using this type of screw with pre-coated screws or you have to use the threadlocker
 | M2 Screw Kit | Amazon.com: Kadrick 304 Stainless Steel Screws,660 Pcs M2 Screw Assortment,Button Head Socket Cap Screws Kit,M2x4mm,6mm,8mm,10mm,12mm,16mm Metric Bolts Nuts Washers Kit with 1 Hex Allen Wrench : Industrial & Scientific |  | $8.99 | 2 | $17.98
 | M2.5 Screw Kit | 705 Pieces M2.5 Screws Nuts Washers Set Black, Sutemribor M2.5 x 4/6/8/10/12/16/20mm Button Head Socket Cap Screws Nuts Washers Assortment Kit, 10.9 Grade Alloy Steel, Fully Threaded: Amazon.com: Industrial & Scientific |  | $9.99 | 1 | $9.99
 | M3 Flat Head Screw Kit | 565 Pieces M3 Screws Nuts Washers Set Black, Sutemribor M3 x 5/6/8/10/12/16/20mm Countersunk Head Socket Cap Screws Nuts Washers Assortment Kit, 10.9 Grade Alloy Steel, Fully Threaded: Amazon.com: Industrial & Scientific |  | $9.99 | 1 | $9.99
 | M3*8 Set Screw | 50 Pcs M3x8mm Metric 304 Stainless Steel Hex Socket Set Flat Point Grub Screws Silver Tone for Towel Rack Door Knob （M3x8mm）: Amazon.com: Industrial & Scientific |  | $6.99 | 1 | $6.99
 | M3*10 Set Screw | 50 Pcs M3x10mm Metric 304 Stainless Steel Hex Socket Set Flat Point Grub Screws Silver Tone for Towel Rack Door Knob （M3x10mm）: Amazon.com: Industrial & Scientific |  | $6.99 | 1 | $6.99
 | M4 Screw Kit | iexcell 675 Pcs M4 x 6/8/10/12/16/20/25/30/35/40 Alloy Steel 10.9 Grade Hex Socket Button Head Cap Screws Bolts Nuts Washers Assortment Kit, Black Oxide Finish: Amazon.com: Industrial & Scientific |  | $22.38 | 1 | $22.38
 | M4 Long Screw Kit | iexcell 50 Pcs M4 x 40/45/50/55/60mm Thread Pitch 0.7 mm Stainless Steel 304 Hex Socket Head Cap Screws Bolts Assortment Kit: Amazon.com: Industrial & Scientific |  | $9.58 | 1 | $9.58
 | M3 and M4 Lock Nuts Kit | 182 Pieces 304 Stainless Steel Lock Nuts |  | $7.98 | 1 | $7.98
 | Vibra-TITE 213 Threadlocker | Amazon.com: Vibra-TITE 213 VC-3 Threadmate Threadlocker, -65 to 165 Degree F, 5mL Tube, Red : Automotive |  | $6.55 | 1 | $6.55
 | Bearing 683 10pcs | uxcell 683-2RS Deep Groove Ball Bearing 3x7x3mm Double Sealed ABEC-3 Bearings 10-Pack: Amazon.com: Industrial & Scientific |  | $11.96 | 1 | $11.96
 | Bearing 684 10pcs | 684ZZ Bearing 4X9X4 mm ABEC-5 (10 PCS) Miniature 684Z Ball Bearings 684 ZZ 618/4ZZ Hobby Emax Motor Quadcopter L-940ZZ Bearing: Amazon.com: Industrial & Scientific |  | $7.99 | 2 | $15.98
 | Bearing AXK0414 | 1Pcs Plane Thrust Needle Roller Bearing AXK0414 0515 0619 0821 1024 1226 1528 1730 2035 2542 3047 3552 4060 To 5070+2AS 2Washers - AliExpress 13 | https://www.amazon.com/uxcell-Bearings-Diameter-Thickness-Steering/dp/B0DQ8T13KV | $1.48 | 30 | $44.40
 | Bushing 3*5*5 10pcs | uxcell Sleeve Bearings 3mm Bore x 5mm OD x 5mm Length Plain Bearings Wrapped Oilless Bushings for Sliding Parts of Machinery, 10pcs: Amazon.com: Industrial & Scientific |  | $5.99 | 1 | $5.99
 | 5mm Rubber Tape | https://www.amazon.com/dp/B0CJRMXN3F?ref=ppx_yo2ov_dt_b_fed_asin_title&th=1 |  | $16.99 | 1 | $16.99
Electronics | Step Down Power Converter 12V 4.5A | Pololu - 12V, 4.5A Step-Down Voltage Regulator D36V50F12 |  | $34.95 | 2 | $69.90
 | USB to Mirco USB Cable 0.5 Feet | https://www.amazon.com/CableCreation-Charger-Compatible-Chromecast-Android/dp/B0CGRG7F2Q?s=industrial |  | $5.98 | 1 | $5.98
 | USB to Mirco USB Cable 1.5 Feet | https://www.amazon.com/dp/B0773N757H?ref=ppx_yo2ov_dt_b_fed_asin_title&th=1 |  | $8.99 | 1 | $8.99
 | USB Hub Port Splitter | https://www.amazon.com/dp/B088KBGRD9?ref=ppx_yo2ov_dt_b_fed_asin_title |  | $6.98 | 1 | $6.98
 | Jumper Wire | https://www.amazon.com/EDGELEC-Breadboard-Optional-Assorted-Multicolored/dp/B07GD2BWPY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 |  | $6.98 | 1 | $6.98
 | JST EH Cable | https://www.digikey.com/short/523wz1nj |  | $0.38 | 10 | $3.82
 | JST EH Housing | https://www.digikey.com/short/zqh51b3r |  | $0.05 | 25 | $1.17
 | 5 Pairs of XT30 Male and Female Plugs | https://www.amazon.com/dp/B09LYHHS9J?ref=ppx_yo2ov_dt_b_fed_asin_title&th=1 |  | $9.99 | 1 | $9.99
 | XT30 to XT60 Male Female 4 pcs | https://www.amazon.com/dp/B07XDTJJLV?ref=ppx_yo2ov_dt_b_fed_asin_title |  | $8.99 | 1 | $8.99
 | Barrel Jack Connector | https://www.amazon.com/Terminal-5-5mm%C3%972-5mm-Connector-Surveillance-Repairs/dp/B0FD9BK96H |  | $9.49 | 1 | $9.49
 | Rocker Switch 5 pcs | https://www.amazon.com/dp/B0C53HD8J7?ref=ppx_yo2ov_dt_b_fed_asin_title&th=1 |  | $5.99 | 1 | $5.99
 | 2000 mAh Lipo Battery | https://www.amazon.com/dp/B0912XDRZJ?starsLeft=1&skipTwisterOG=1 |  | $49.99 | 1 | $49.99
 | Lipo Battery Voltage Tester | https://www.amazon.com/dp/B07DC3LH9C?ref=ppx_yo2ov_dt_b_fed_asin_title |  | $12.95 | 1 | $12.95
 | Lipo Battery Balance Charger | https://www.amazon.com/dp/B09XC91BWJ?ref=ppx_yo2ov_dt_b_fed_asin_title |  | $31.99 | 1 | $31.99
 | 14 AWG Power Extension Cable | https://www.amazon.com/Electrical-Conductor-Flexible-Parallel-Extension/dp/B088RDY284?s=industrial |  | $17.49 | 1 | $17.49
Materials | PLA-CF 1KG | https://us.store.bambulab.com/collections/carbon-fiber/products/pla-cf?variant=41003202248840 |  | $34.99 | 2 | $69.98
 | PLA 1KG | https://us.store.bambulab.com/products/pla-basic-filament |  | $19.99 | 1 | $19.99
 |  |  |  |  |  | $5,727.94 | $7,293.56
 |  |  |  |  |  | 2XC | 2XM
Tools
3D-Printing | Bambu Lab X1-Carbon Combo 3D Printer | https://us.store.bambulab.com/products/x1-carbon-combo |  | $1,449.00 | 1 | $1,449.00
 | Bambu Smooth PEI Plate | https://us.store.bambulab.com/products/bambu-smooth-pei-plate |  | $37.99 | 1 | $37.99
 | Liquid Glue for Build Plate | https://us.store.bambulab.com/products/liquid-glue-for-build-plate?_pos=2&_sid=7c0e9c004&_ss=r |  | $16.99 | 1 | $16.99
 | Anti-vibration Foot | https://us.store.bambulab.com/products/anti-vibration-feet-for-p1p |  | $10.99 | 1 | $10.99
Power | 30V 10A Power Supply | https://www.amazon.com/Programmable-Precision-Multiple-Protection-Software/dp/B0928LX2D1?s=industrial |  | $119.99 | 1 | $119.99
 | Banana Plug Cables | https://www.amazon.com/Sumnacon-Multimeter-Crocodile-Alligator-Stackable/dp/B071SL6PQS |  | $9.99 | 1 | $9.99
Hardware | Screwdriver Kit | https://www.amazon.com/dp/B0BLMQ8BXB?starsLeft=1&ref_=cm_sw_r_cso_cp_apin_dp_RDJBS7WAX5ERNPW5P4YK |  | $64.99 | 1 | $64.99
 | Precision Screwdriver Kit | https://www.amazon.com/HOTO-Screwdriver-Precision-Rechargeable-Electronics/dp/B09MR5HFPB |  | $29.99 | 1 | $29.99
 | Allen Key Set | https://www.amazon.com/Edward-Tools-Piece-Short-Wrench/dp/B09PC433HS?s=hi |  | $6.95 | 1 | $6.95
 | Pliers | https://www.amazon.com/Professional-Cutters-Diagonal-Repairing-Crafting/dp/B07R8JLJVR |  | $32.35 | 1 | $32.35
 | Caliper Digital | https://www.amazon.com/Measuring-Stainless-Micrometer-Fraction-Household/dp/B0BF9LW56V |  | $29.98 | 1 | $29.98
 | Double Sided Tape | https://www.amazon.com/BYUEE-30-Yards-Adhesive-Scrapbooking-Wrapping/dp/B07MZQC1T2?s=hi |  | $9.99 | 1 | $9.99
Soldering | Automatic Wire Stripper | https://www.amazon.com/VCELINK-Automatic-Stripper-Professional-Adjustable/dp/B08G48R47N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 |  | $9.99 | 1 | $9.99
 | Soldering Tweezer | https://www.amazon.com/Precision-Anti-Static-Electronics-Sodlering%EF%BC%8CJewelry-Laboratory/dp/B0BHP5S82C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 |  | $5.99 | 1 | $5.99
 | Soldering Brass | https://www.amazon.com/Weller-WLACCBSH-02-Soldering-Cleaner-Silicone/dp/B08FQBS97L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 |  | $11.97 | 1 | $11.97
 | Soldering Station | https://www.amazon.com/gp/product/B07XC9VV2C/ref=ppx_yo_dt_b_search_asin_title?ie=UTF8&th=1 |  | $69.99 | 1 | $69.99
 | Black Silicone Repair Mat | https://www.amazon.com/gp/product/B08RXMDKWX/ref=ppx_yo_dt_b_search_asin_title?ie=UTF8&th=1 |  | $8.53 | 1 | $8.53
 | Heat Shrink Tube | https://www.amazon.com/Ginsco-580-pcs-Assorted-Sleeving/dp/B01MFA3OFA |  | $6.99 | 1 | $6.99
 | Heat Shrink Butt Connectors 100 pcs | https://www.amazon.com/gp/product/B07GDDKJ1D/ref=ppx_yo_dt_b_search_asin_title?ie=UTF8&th=1 |  | $9.49 | 1 | $9.49
 | Helping Hands Soldering | https://www.amazon.com/gp/product/B07MDKXNPC/ref=ppx_yo_dt_b_search_asin_title?ie=UTF8&th=1 |  | $23.99 | 1 | $23.99
 | 60/40 Tin Lead Solder Wire | https://www.amazon.com/gp/product/B07BGTSWYB/ref=ppx_yo_dt_b_search_asin_title?ie=UTF8&th=1 |  | $9.99 | 1 | $9.99
 |  |  |  |  |  | $1,976.13
Additional Features
Safety Stand | 20 Set 4040 Connector | https://www.amazon.com/4040-Connector-Corner-Reinforcing-20/dp/B0BS6MG9D5?sp_csd=d2lkZ2V0TmFtZT1zcF9hdGY |  | $24.99 | 1 | $24.99
 | 4040 Aluminum Extrusion 500mm | https://www.amazon.com/Seekliny-Aluminum-Extrusion-T-Slotted-Accessories/dp/B0CP1XF8XM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 |  | $55.99 | 1 | $55.99
 | M5 T-Nuts Screws Kit 200pcs | https://www.amazon.com/Aluminum-Extrusion-Hexagon-Sliding-Washers/dp/B0C4JTL1MP?sp_csd=d2lkZ2V0TmFtZT1zcF9tdGY |  | $13.99 | 1 | $13.99
 | 2020 Aluminum Extrusion 100mm | https://www.amazon.com/European-Standard-Anodized-Aluminum-Extrusion/dp/B09JSN97Y9 |  | $18.99 | 1 | $18.99
Teleoperation | DYNAMIXEL 2XL430-W250-T | https://www.robotis.us/dynamixel-2xl430-w250-t/ |  | $129.90 | 6 | $779.40
 | DYNAMIXEL XC430-T240BB-T | https://www.robotis.us/dynamixel-xc430-t240bb-t/ |  | $119.99 | 2 | $239.98
 | Dynamixel U2D2 USB Comm Module | https://www.robotis.us/u2d2/ |  | $32.10 | 1 | $32.10
 | Dynamixel U2D2 Power Hub Board Set | https://www.robotis.us/u2d2-power-hub-board-set/ |  | $19.00 | 1 | $19.00
 | Breadboard Kit | https://www.amazon.com/ELEGOO-Breadboard-Solderless-Breadboards-Electronics/dp/B0CYPVMK9J |  | $6.99 | 1 | $6.99
 | LilyGo T-Display S3 | https://www.amazon.com/dp/B09J112YR7?ref=ppx_yo2ov_dt_b_fed_asin_title&th=1 |  | $27.50 | 1 | $27.50
 | Round Force Sensitive Resistor (FSR) | https://www.adafruit.com/product/5475 |  | $4.46 | 2 | $8.92
 | Resistor Kit | https://www.amazon.com/BOJACK-Values-Resistor-Resistors-Assortment/dp/B08FD1XVL6?s=industrial |  | $9.99 | 1 | $9.99
 | E stop Switch | https://www.amazon.com/dp/B09B2441R7?ref=ppx_yo2ov_dt_b_fed_asin_title |  | $6.99 | 1 | $6.99
 | Rog Ally X | https://www.bestbuy.com/site/asus-rog-ally-x-7-120hz-fhd-1080p-gaming-handheld-amd-ryzen-z1-extreme-processor-24gb-with-1tb-ssd-black/6583218.p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 |  | $900.00 | 1 | $900.00
Battery | 21700 Cell | https://mabdelectronics.com/products/samsung-21700-50s-25a-5000mah-battery?variant=44357994479862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 |  | $8.49 | 6 | $50.94
 | 21700 Battery Holder | https://www.amazon.com/dp/B0BSDC7L9T?ref=ppx_yo2ov_dt_b_fed_asin_title |  | $12.99 | 1 | $12.99
 | JST XH balancing plug | https://www.amazon.com/Connector-pre-crimped-Housing-Adapter-Compatible/dp/B08G188ZQ8 |  | $16.99 | 1 | $16.99
SysID | Portable Bench Clamp | https://www.amazon.com/dp/B09ZKF5WR7?ref=ppx_yo2ov_dt_b_fed_asin_title |  | $26.98 | 1 | $26.98
 |  |  |  |  |  | $2,252.73

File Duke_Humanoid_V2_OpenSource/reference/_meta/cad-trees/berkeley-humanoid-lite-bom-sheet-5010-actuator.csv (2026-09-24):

Category | Item | Description | Quantity | Cost USD | Total Cost USD | US Link | Cost RMB | Total Cost RMB | China Link
Bearing | MR106-2RS | Bearing between input shaft and cycloidal disk, and between input shaft and output shaft | 13 | $0.87 | $11.31 | https://www.amazon.com/dp/B082PSCNKB?ref_=cm_sw_r_cp_ud_dp_XR6N8JQ34JH0ZSWHT5HK | ¥0.90 | ¥11.70 | https://detail.tmall.com/item.htm?abbucket=9&id=728753970557&skuId=5050168324949
 | 6701-2RS | Bearing between cycloidal disk and output shaft | 2 | $0.94 | $1.88 | https://www.amazon.com/gp/product/B082PQ8DC2 | ¥2.30 | ¥4.60 | https://detail.tmall.com/item.htm?abbucket=9&id=672836796497&skuId=5017505094887
 | 6809ZZ | Bearing between output shaft and housing | 2 | $2.26 | $4.52 | https://www.amazon.com/gp/product/B082PQQP7W | ¥3.89 | ¥7.78 | https://detail.tmall.com/item.htm?abbucket=8&id=695287603935&ns=1&skuId=5102438922481
Fastener | M3 x 55 mm | Mounting housing | 4 | $0.26 | $1.04 | https://www.amazon.com/gp/product/B01N68JLPE/ | ¥0.35 | ¥1.40 | https://detail.tmall.com/item.htm?abbucket=8&id=654819932601&skuId=5014407101270
 | M3 x 25 mm | Mounting output shaft | 6 | $0.19 | $1.14 | https://www.amazon.com/gp/product/B0967ZWJMM | ¥0.07 | ¥0.42 | https://detail.tmall.com/item.htm?abbucket=8&id=654819932601&skuId=5014407101291
 | M2 x 3 x 3.5 mm | M2 threaded insert for mounting encoder | 4 | $0.07 | $0.28 | https://www.amazon.com/dp/B0B8GN63S2 | ¥0.08 | ¥0.32 | https://detail.tmall.com/item.htm?abbucket=15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
 | M3 x 4 x 5 mm insert | M3 threaded insert | 24 | $0.08 | $1.92 | https://www.amazon.com/gp/product/B0BTYF2MMD | ¥0.13 | ¥3.12 | https://item.taobao.com/item.htm?id=593581996419&skuId=4189077672129
 | M4 x 12 mm hex stand | input shaft stiffener | 1 | $0.40 | $0.40 | https://www.amazon.com/uxcell-Female-Threaded-Standoff-Pillar/dp/B018RSONJK?s=industrial | ¥0.26 | ¥0.26 | https://detail.tmall.com/item.htm?abbucket=8&id=645528391157
Motor | MAD Components 5010 110KV |  | 1 | $84.00 | $84.00 | https://www.amazon.com/gp/product/B082W5B5LZ | ¥448.00 | ¥448.00 | https://item.taobao.com/item.htm?abbucket=8&id=534590842464
Structural | PLA | 3D print filament, in kg | 0.1 | $25.99 | $2.60 | https://www.amazon.com/gp/product/B00J0GMMP6 | ¥79.00 | ¥7.90 | https://detail.tmall.com/item.htm?abbucket=8&id=693972799714
Electrical | B-G431B-ESC1 | Motor controller | 1 | $18.97 | $18.97 | https://www.digikey.com/en/products/detail/stmicroelectronics/B-G431B-ESC1/10321670 | ¥165.00 | ¥165.00 | https://item.taobao.com/item.htm?abbucket=8&id=656153143517
 | AS5600 | I2C position encoder | 1 | $3.30 | $3.30 | https://www.amazon.com/gp/product/B09LMB3PTZ | ¥5.40 | ¥5.40 | https://item.taobao.com/item.htm?abbucket=8&id=828546819482
 | Misc | Cables & connectors | 1 | $5.00 | $5.00 |  | ¥20.00 | ¥20.00
Total |  |  |  |  | $136.36 |  |  | ¥675.90
 |  |  |  |  |  |  |  | $95.20

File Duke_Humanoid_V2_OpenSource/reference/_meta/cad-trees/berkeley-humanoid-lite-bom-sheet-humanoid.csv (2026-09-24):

Category | Item | Description | Quantity | Cost USD | Total Cost USD | US Link | Cost RMB | Total Cost RMB | China Link
Base | Mini PC |  | 1 | $129.00 | $129.00 | https://www.amazon.com/gp/product/B0BVLPCDVW | ¥1,599.00 | ¥1,599.00 | https://item.taobao.com/item.htm?abbucket=8&id=717966676915
 | LiPo battery 6S |  | 1 | $70.20 | $70.20 | https://www.amazon.com/Zeee-Connector-Airplane-Helicopter-Quadcopter/dp/B0DGPMD46S | ¥578.00 | ¥578.00 | https://item.taobao.com/item.htm?id=554987950181&skuId=4800836808256
 | USB-CAN adapter |  | 4 | $16.99 | $67.96 | https://www.amazon.com/gp/product/B0BPY5HY6C | ¥77.00 | ¥308.00 | https://item.taobao.com/item.htm?abbucket=8&id=694755138362
 | USB hub |  | 2 | $17.99 | $35.98 | https://www.amazon.com/gp/product/B07L32B9C2 | ¥39.90 | ¥79.80 | https://detail.tmall.com/item.htm?abbucket=8&id=630445232755&
 | BNO085 | IMU sensor | 1 | $12.76 | $12.76 | https://www.amazon.com/YZYDF-Practical-Precisions-GY-ICM20948V2-Magnetometer/dp/B0DP4KXZQM | ¥84.00 | ¥84.00 | https://detail.tmall.com/item.htm?abbucket=8&id=658253576279&skuId=5473425713581
 | IM10A | Alternative IMU sensor, easier to wire | 1 | $89.99 | -- | https://www.hiwonder.com/products/imu-module?variant=40375875338327 | ¥248.00 | -- | https://detail.tmall.com/item.htm?priceTId=2100c89817507961008695158e0a40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
 | Aluminum extrusion 250 mm |  | 2 | $4.25 | $8.50 | https://www.amazon.com/Aluminum-Extrusion-European-Standard-15-75inch/dp/B08Y8L11ZP | ¥2.83 | ¥5.66 | https://item.taobao.com/item.htm?abbucket=8&id=690128619754
 | Aluminum extrusion 200 mm |  | 4 | $3.75 | $15.00 | https://www.amazon.com/Aluminum-Extrusion-European-Standard-15-75inch/dp/B08Y8KL79L | ¥2.26 | ¥9.04 | https://item.taobao.com/item.htm?abbucket=8&id=690128619754
 | Aluminum extrusion 150 mm |  | 2 | $3.00 | $6.00 | https://www.amazon.com/Aluminum-Extrusion-European-Standard-15-75inch/dp/B08Y8KTZ2Z | ¥1.70 | ¥3.40 | https://item.taobao.com/item.htm?abbucket=8&id=690128619754
 | Aluminum extrusion 100 mm |  | 3 | $3.25 | $9.75 | https://www.amazon.com/European-Standard-Anodized-Aluminum-Extrusion/dp/B09JSN97Y9 | ¥1.20 | ¥3.60 | https://item.taobao.com/item.htm?abbucket=8&id=690128619754
 | Aluminum inner bracket |  | 24 | $0.65 | $15.60 | https://www.amazon.com/gp/product/B07872XFWF | ¥0.70 | ¥16.80 | https://item.taobao.com/item.htm?id=819016158292&skuId=5692325483198
 | 24V to 12V regulator |  | 1 | $16.99 | $16.99 | https://www.amazon.com/Stabilizer-DROK-Waterproof-Transformer-Television/dp/B081RG8XP5 | ¥14.00 | ¥14.00 | https://item.taobao.com/item.htm?id=626418952771&skuId=4619768987075
 | 12V to 5V regulator |  | 1 | $4.49 | $4.49 | https://www.amazon.com/dp/B08FHYK1PB | ¥10.79 | ¥10.79 | https://detail.tmall.com/item.htm?abbucket=15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
 | Voltage monitor |  | 1 | $14.99 | $14.99 | https://www.amazon.com/gp/product/B09G6QHPPJ/ | ¥3.60 | ¥3.60 | https://detail.tmall.com/item.htm?abbucket=8&id=647059163846&skuId=4830044502772
 | Current monitor |  | 1 | $20.98 | $20.98 | https://www.amazon.com/gp/product/B01DDQM6Z4 | ¥13.90 | ¥13.90 | https://item.taobao.com/item.htm?abbucket=8&id=43511429194&skuId=3106569940562
 | Circuit breaker |  | 1 | $19.99 | $19.99 | https://www.amazon.com/gp/product/B07SHB3TS5 | ¥66.00 | ¥66.00 | https://item.taobao.com/item.htm?abbucket=8&id=708760411946&skuId=5147276763391
 | Misc | Fasteners | 1 | $40.00 | $40.00 |  | ¥85.00 | ¥85.00
 | Misc | Cables & connectors | 1 | $50.00 | $50.00 |  | ¥100.00 | ¥100.00
Legs | M6C12 actuators |  | 8 | $188.69 | $1,509.51 |  | ¥1,122.76 | ¥8,982.08
 | 5010 actuators |  | 4 | $136.36 | $545.44 |  | ¥675.90 | ¥2,703.60
 | 3D print filament |  | 1 | $100.00 | $100.00 |  | ¥300.00 | ¥300.00
 | 6803-2RS | Bearing between the linkage on the pitch actuators on legs | 6 | $2.87 | $17.22 | https://www.amazon.com/dp/B09P21T5QV | ¥1.20 | ¥7.20 | https://item.taobao.com/item.htm?id=611641987734&skuId=4305314537774
Arms | M6C12 actuators |  | 2 | $188.69 | $377.38 |  | ¥1,122.76 | ¥2,245.52
 | 5010 actuators |  | 8 | $136.36 | $1,090.87 |  | ¥675.90 | ¥5,407.20
 | Servo motor claw |  | 2 | $35.99 | $71.98 | https://www.amazon.com/LewanSoul-Mechanical-BigClaw-Gripper-Without/dp/B0CMHV5DZ3 | ¥159.00 | ¥318.00 | https://detail.tmall.com/item.htm?abbucket=8&id=600961750206&skuId=4202414349841
 | 3D print filament |  | 1 | $100.00 | $100.00 |  | ¥300.00 | ¥300.00
Total |  |  |  |  | $4,350.59 |  |  | ¥23,244.19

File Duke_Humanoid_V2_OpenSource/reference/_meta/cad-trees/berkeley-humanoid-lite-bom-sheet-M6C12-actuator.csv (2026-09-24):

Category | Item | Description | Quantity | Cost USD | Total Cost USD | US Link | Cost RMB | Total Cost RMB | China Link
Bearing | MR106-2RS | Bearing between input shaft and cycloidal disk, and between input shaft and output shaft | 13 | $0.87 | $11.31 | https://www.amazon.com/dp/B082PSCNKB?ref_=cm_sw_r_cp_ud_dp_XR6N8JQ34JH0ZSWHT5HK | ¥0.90 | ¥11.70 | https://detail.tmall.com/item.htm?abbucket=9&id=728753970557&skuId=5050168324949
 | 6701-2RS | Bearing between cycloidal disk and output shaft | 2 | $0.94 | $1.88 | https://www.amazon.com/gp/product/B082PQ8DC2 | ¥2.30 | ¥4.60 | https://detail.tmall.com/item.htm?abbucket=9&id=672836796497&skuId=5017505094887
 | 6811ZZ | Bearing between output shaft and housing | 2 | $5.00 | $10.00 | https://www.amazon.com/gp/product/B082PW8F3S | ¥5.83 | ¥11.66 | https://detail.tmall.com/item.htm?abbucket=8&id=695287603935&ns=1&skuId=5102438922487
Fastener | M3 x 55 mm | Mounting housing | 8 | $0.26 | $2.08 | https://www.amazon.com/gp/product/B01N68JLPE/ | ¥0.35 | ¥2.80 | https://detail.tmall.com/item.htm?abbucket=8&id=654819932601&skuId=5014407101270
 | M3 x 30 mm | Mounting output shaft | 6 | $0.19 | $1.14 | https://www.amazon.com/gp/product/B0968155BV | ¥0.07 | ¥0.42 | https://detail.tmall.com/item.htm?abbucket=8&id=654819932601&skuId=5014407101253
 | M2 x 3 x 3.5 mm | M2 threaded insert for mounting encoder | 4 | $0.07 | $0.28 | https://www.amazon.com/dp/B0B8GN63S2 | ¥0.08 | ¥0.32 | https://detail.tmall.com/item.htm?abbucket=15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
 | M3 x 4 x 5 mm insert | M3 threaded insert | 24 | $0.08 | $1.92 | https://www.amazon.com/gp/product/B0BTYF2MMD | ¥0.13 | ¥3.12 | https://item.taobao.com/item.htm?id=593581996419&skuId=4189077672129
 | M4 x 15 mm hex stand | input shaft stiffener | 1 | $0.69 | $0.69 | https://www.amazon.com/Aexit-Spacers-Standoffs-Female-Standoff/dp/B07DRGBZTH?s=industrial | ¥0.26 | ¥0.26 | https://detail.tmall.com/item.htm?abbucket=8&id=645528391157
Motor | MAD Components M6C12 150KV |  | 1 | $129.00 | $129.00 | https://www.amazon.com/MAD-COMPONENTS-Antimatter-Multirotor-Quadcopter/dp/B08GQ6Q464 | ¥888.00 | ¥888.00 | https://item.taobao.com/item.htm?abbucket=8&id=650930600496
Structural | PLA | 3D print filament, in kg | 0.12 | $25.99 | $3.12 | https://www.amazon.com/gp/product/B00J0GMMP6 | ¥79.00 | ¥9.48 | https://detail.tmall.com/item.htm?abbucket=8&id=693972799714
Electrical | B-G431B-ESC1 | Motor controller | 1 | $18.97 | $18.97 | https://www.digikey.com/en/products/detail/stmicroelectronics/B-G431B-ESC1/10321670 | ¥165.00 | ¥165.00 | https://item.taobao.com/item.htm?abbucket=8&id=656153143517
 | AS5600 | I2C position encoder | 1 | $3.30 | $3.30 | https://www.amazon.com/gp/product/B09LMB3PTZ | ¥5.40 | ¥5.40 | https://item.taobao.com/item.htm?abbucket=8&id=828546819482
 | Misc | Cables & connectors | 1 | $5.00 | $5.00 |  | ¥20.00 | ¥20.00
Total |  |  |  |  | $188.69 |  |  | ¥1,122.76
 |  |  |  |  |  |  |  | $158.14

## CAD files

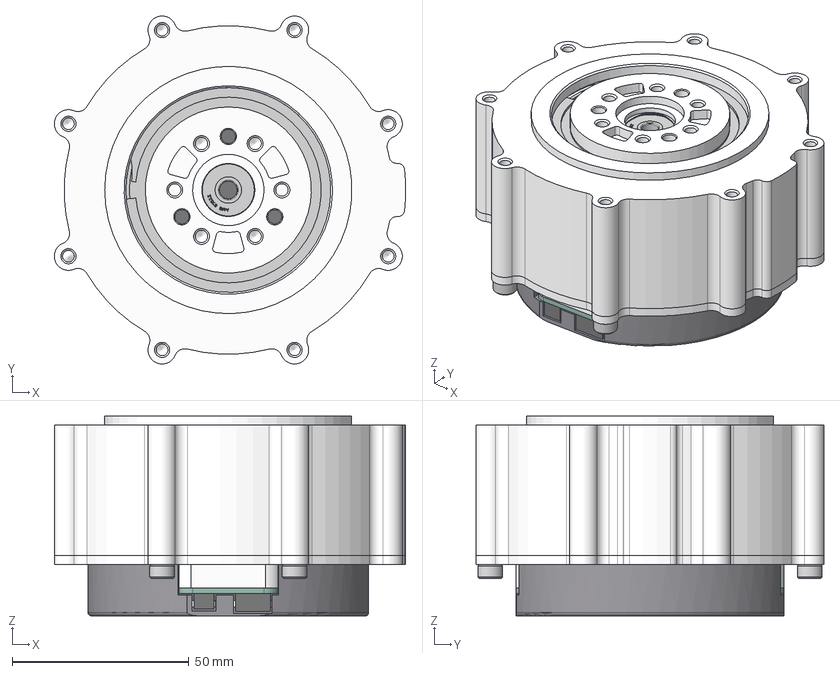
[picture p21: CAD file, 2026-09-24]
Duke_Humanoid_V2_OpenSource/hardware-site/docs/files/modules/robstride-03-full_rev01.step
99.5 x 98.5 x 56.6 mm

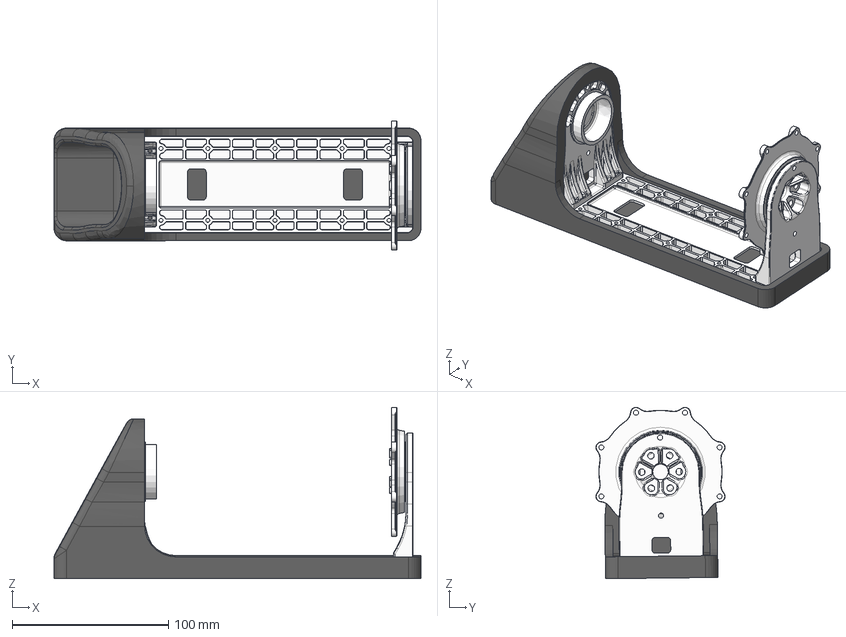
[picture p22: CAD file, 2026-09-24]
Duke_Humanoid_V2_OpenSource/hardware-site/docs/files/modules/foot-assembly_rev01.step
235.0 x 82.8 x 109.8 mm

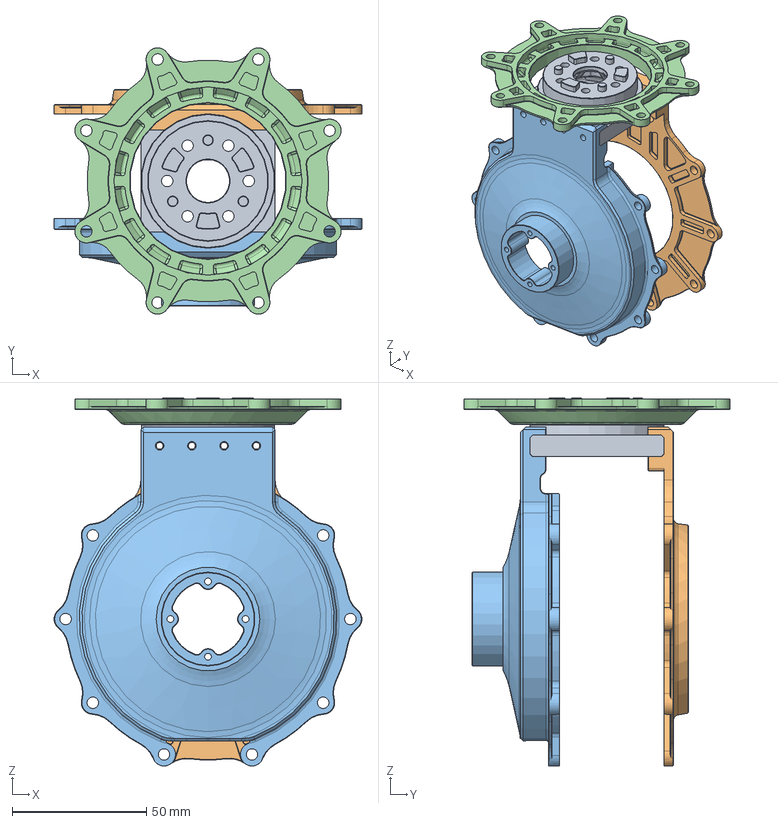
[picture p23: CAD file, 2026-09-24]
Duke_Humanoid_V2_OpenSource/hardware-site/docs/files/modules/knee-assembly_rev01.step
114.6 x 99.1 x 137.0 mm

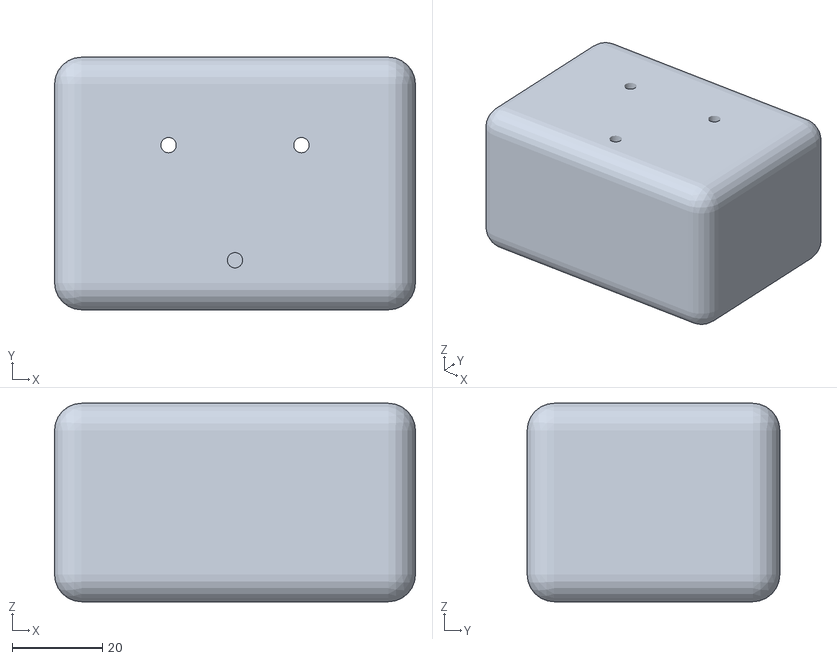
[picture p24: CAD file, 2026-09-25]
assets/print/3DP_grp01_gripper_body_v0_2.stl
80.0 x 56.0 x 44.0

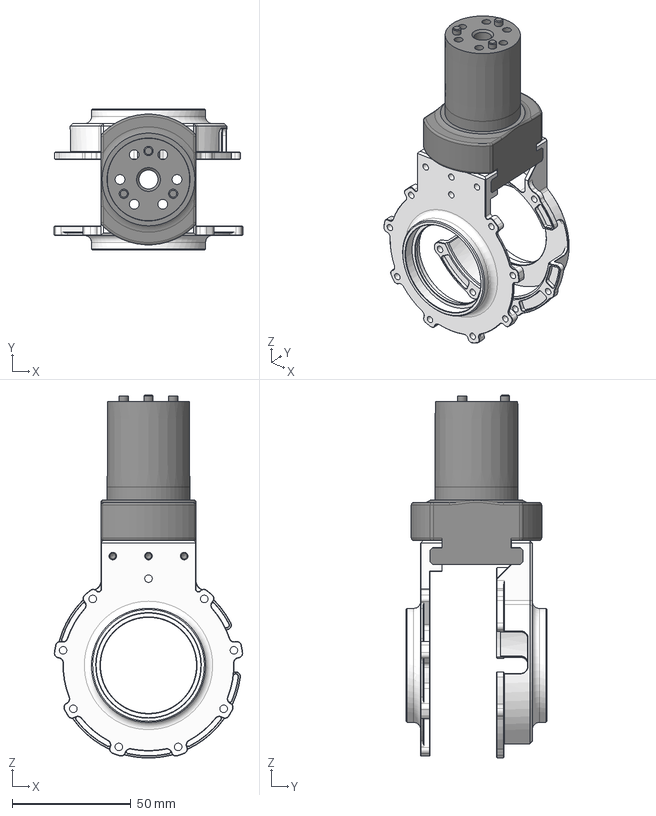
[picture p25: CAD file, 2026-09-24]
Duke_Humanoid_V2_OpenSource/hardware-site/docs/files/modules/shoulder-yaw-elbow_rev01.step
79.3 x 59.5 x 152.7 mm

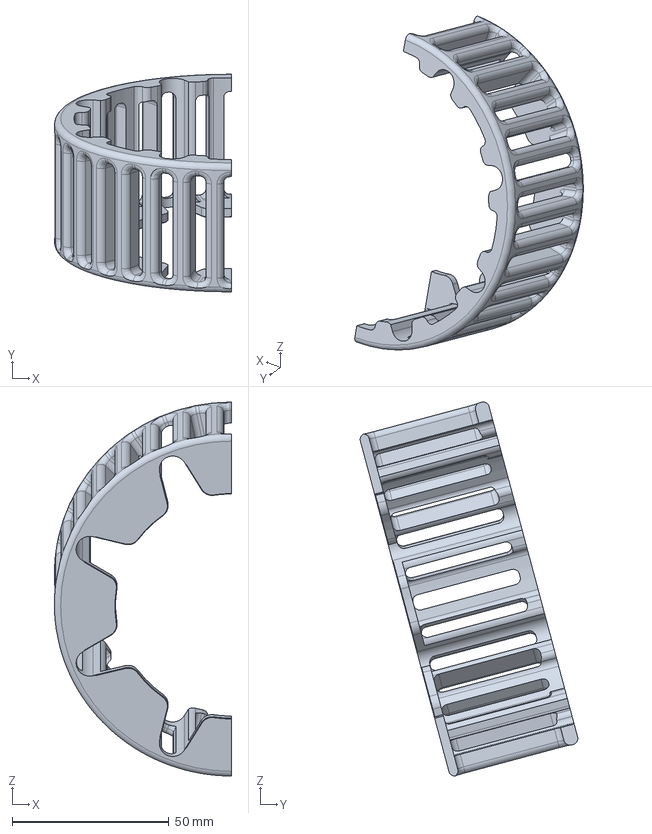
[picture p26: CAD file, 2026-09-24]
Duke_Humanoid_V2_OpenSource/hardware-site/docs/files/step/3DP_legP01_hip3_cover_a_rev01.step
56.5 x 69.4 x 119.2 mm

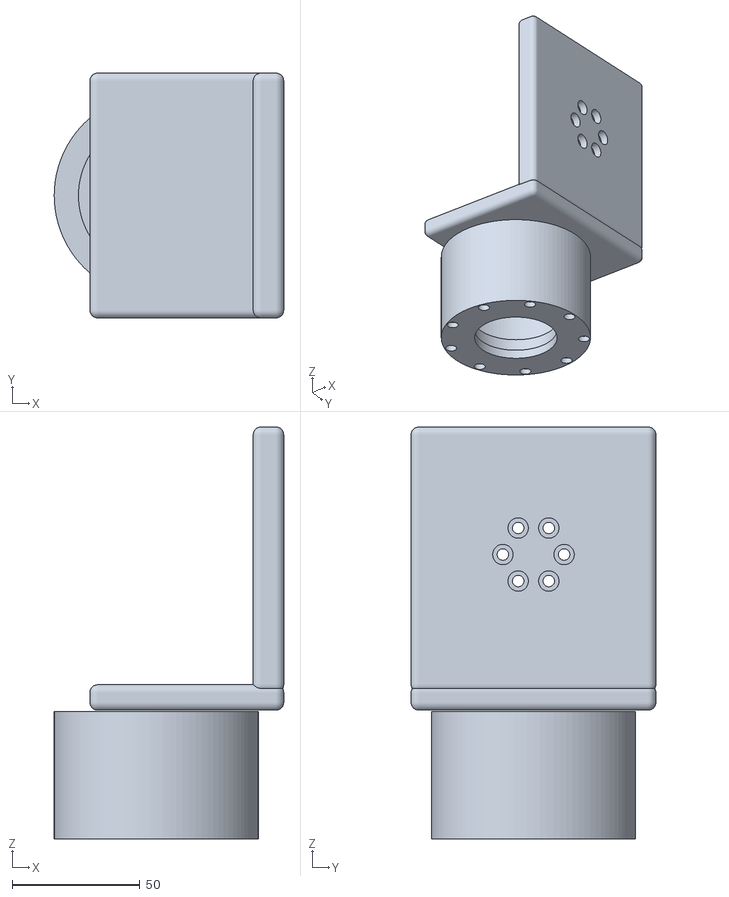
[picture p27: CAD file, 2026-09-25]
assets/print/3DP_arm04_upper_arm_yoke_v0_2.stl
90.0 x 96.0 x 161.5

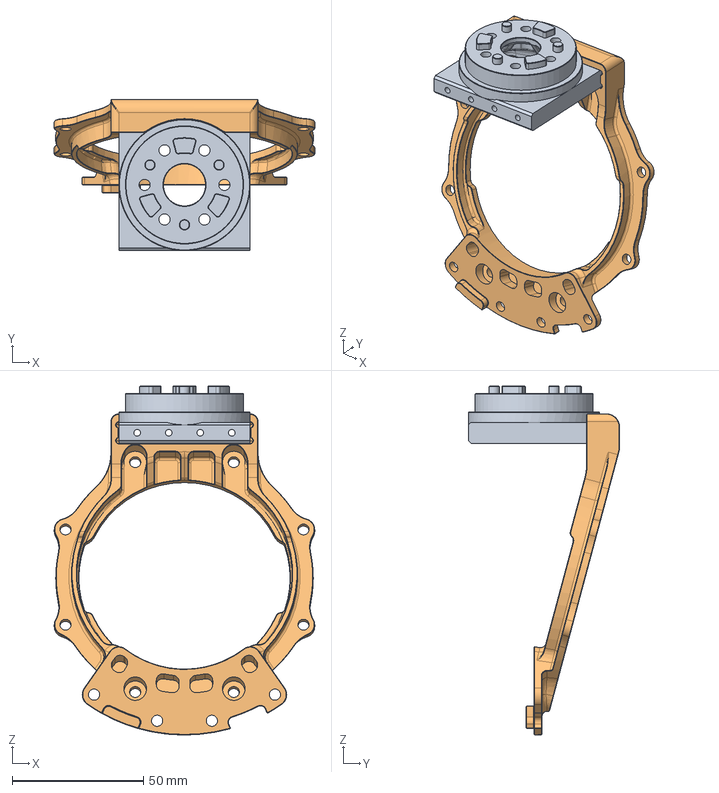
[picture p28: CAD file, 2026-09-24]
Duke_Humanoid_V2_OpenSource/hardware-site/docs/files/modules/hip-center_rev01.step
99.1 x 57.5 x 132.8 mm
CNC_leg02_x7_RS03_shaft_coupler

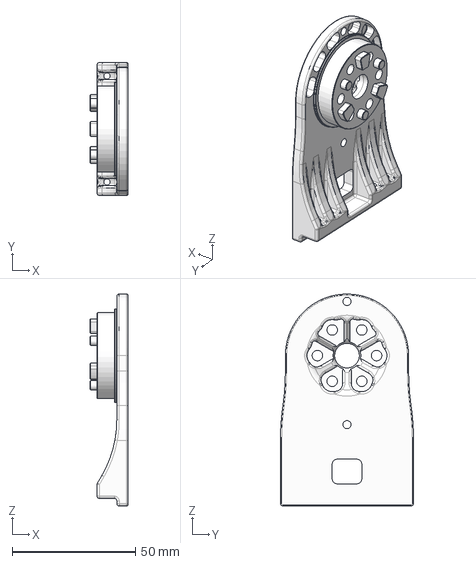
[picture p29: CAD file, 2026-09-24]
Duke_Humanoid_V2_OpenSource/hardware-site/docs/files/step/CNC_leg16_ankle_roll_output_shaft_rev01.step
15.3 x 54.0 x 86.0 mm

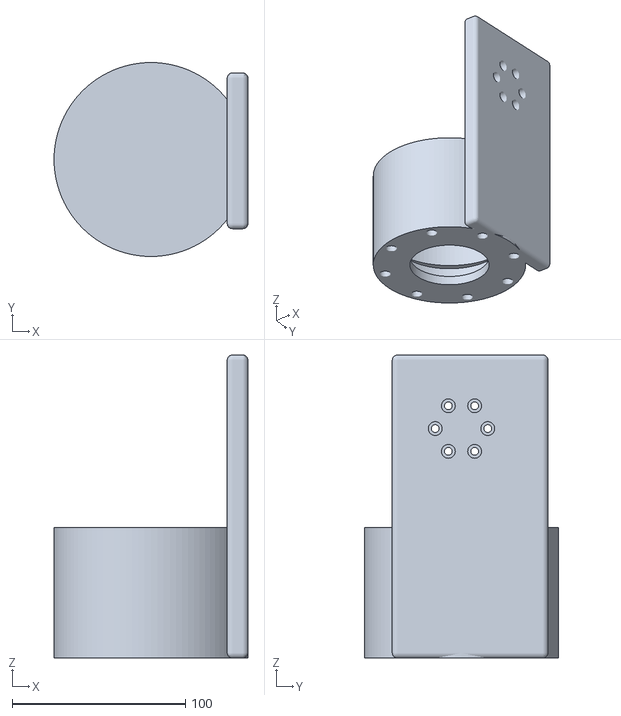
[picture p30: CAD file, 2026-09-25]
assets/print/3DP_leg04_hip_yaw_housing_v0_2.stl
112.0 x 112.0 x 175.0

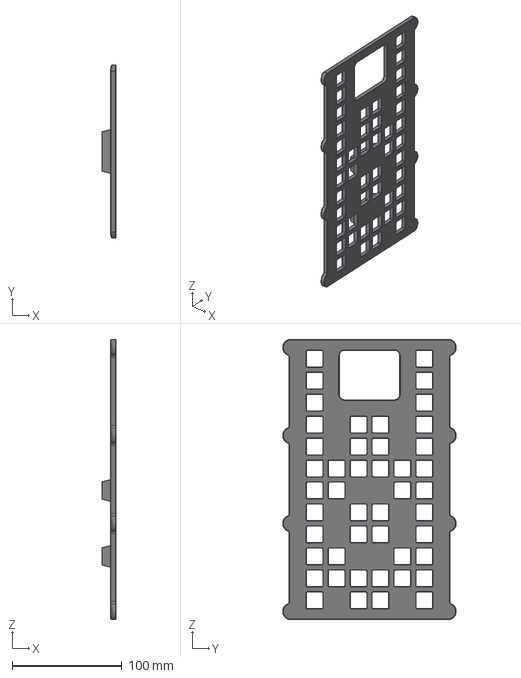
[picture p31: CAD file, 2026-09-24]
Duke_Humanoid_V2_OpenSource/hardware-site/docs/files/modules/3dp-body-09-x1-back-plate-removable_rev01.step
13.0 x 157.8 x 254.7 mm
magnet_1/2inD_1/16inT x 14

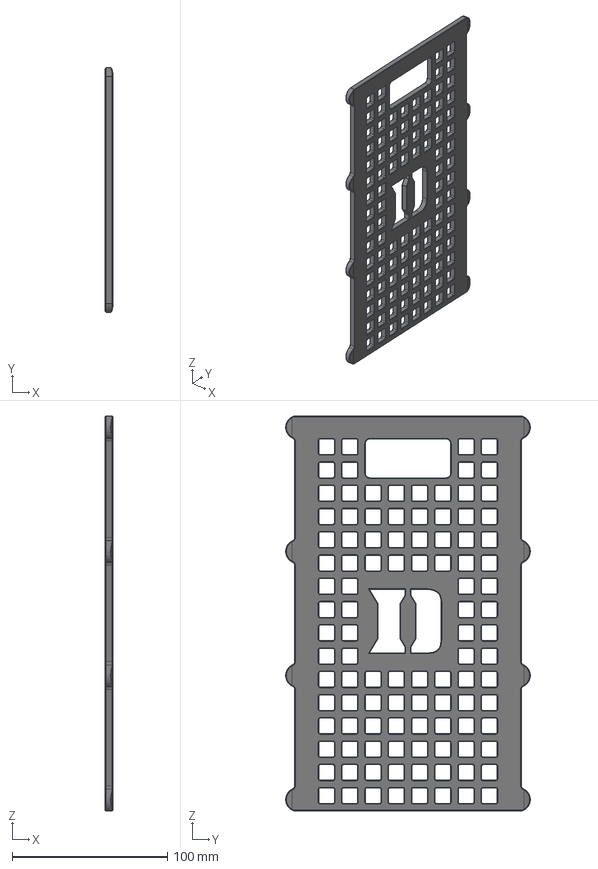
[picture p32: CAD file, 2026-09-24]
Duke_Humanoid_V2_OpenSource/hardware-site/docs/files/step/3DP_body07_front_plate_removable_rev01.step
5.00 x 157.8 x 254.7 mm
magnet_1/2inD_1/16inT x 8

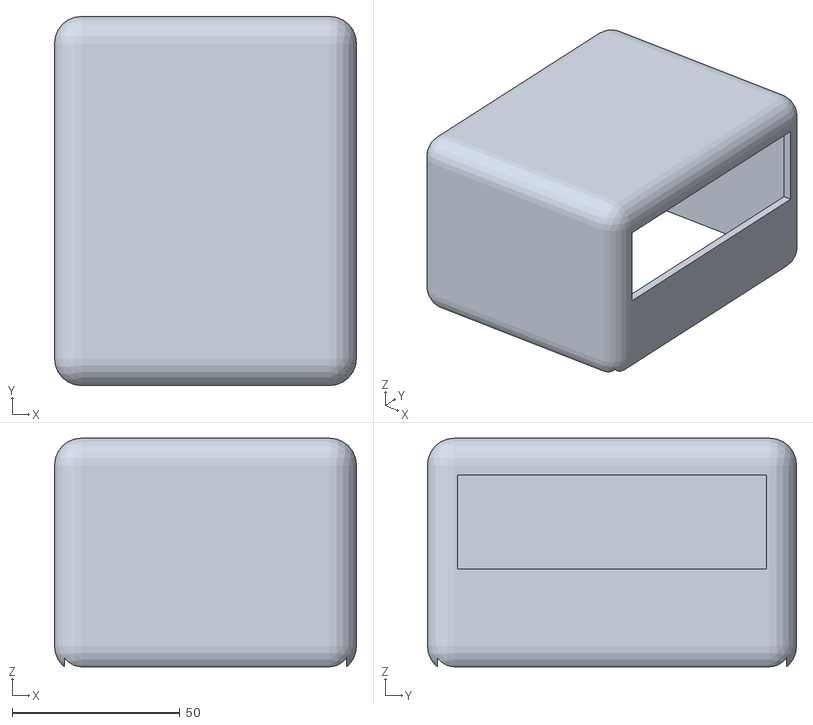
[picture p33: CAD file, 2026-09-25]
assets/print/3DP_hea02_head_shell_v0_2.stl
90.0 x 110.0 x 68.2

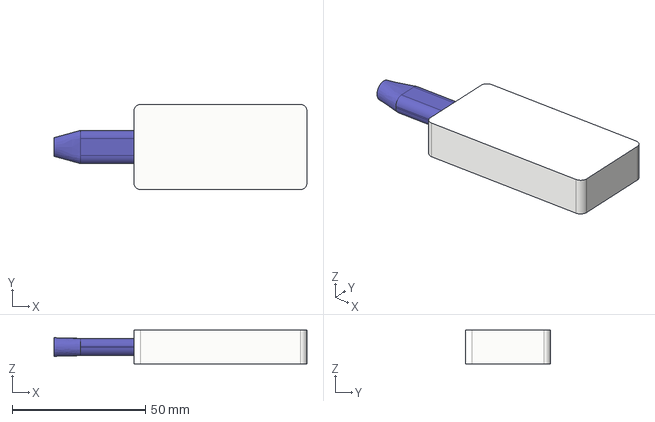
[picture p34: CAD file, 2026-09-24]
Duke_Humanoid_V2_OpenSource/hardware-site/docs/files/modules/can-isolated_rev01.step
95.0 x 32.0 x 12.8 mm

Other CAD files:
Duke_Humanoid_V2_OpenSource/hardware-site/docs/files/step/3DP_armP02_elbow_cover_b_rev01.step
assets/print/3DP_pel01_pelvis_shell_v0_2.stl
Duke_Humanoid_V2_OpenSource/hardware-site/docs/files/modules/shoulder-roll-shaft_rev01.step
Duke_Humanoid_V2_OpenSource/hardware-site/docs/files/step/3DP_grip02_finger_rev01.step
Duke_Humanoid_V2_OpenSource/hardware-site/docs/files/modules/001-left-wrist-long-latest_rev01.step
Duke_Humanoid_V2_OpenSource/hardware-site/docs/files/modules/001-right-wrist-long-latest_rev01.step
Duke_Humanoid_V2_OpenSource/hardware-site/docs/files/modules/3dp-arm06-x4-rs02-shaft-coupler-2_rev01.step
Duke_Humanoid_V2_OpenSource/hardware-site/docs/files/modules/3dp-arm06-x4-rs02-shaft-coupler_rev01.step
Duke_Humanoid_V2_OpenSource/hardware-site/docs/files/modules/3dp-body-05-x1-interior-plate_rev01.step
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

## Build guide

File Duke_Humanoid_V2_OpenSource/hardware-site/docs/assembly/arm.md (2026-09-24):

# Arm

One seven-joint arm, shoulder to wrist. Build two; the second is the mirror of the first. Grippers go on in [Final integration](#final-integration).

!!! abstract "At a glance"
    - **You will:** set seven IDs, build shoulder, elbow and wrist, then fit the covers.
    - **Before this:** [Leg](#leg).

{{ step(1, "Set the seven actuator IDs") }}

Set and label each ID on the bench, one actuator at a time. `shoulder_1` is on the torso bus `can22`, not the arm's own bus.

| Joint | Actuator | ID left / right | Bus left / right |
| --- | --- | --- | --- |
| `shoulder_1` (pitch) | RobStride 03 | 10 / 20 | `can22` / `can22` |
| `shoulder_2` (roll) | RobStride 06 | 11 / 21 | `can9` / `can21` |
| `shoulder_3` (yaw) | RobStride 02 | 12 / 22 | `can9` / `can21` |
| `elbow` | RobStride 02 | 13 / 23 | `can9` / `can21` |
| `wrist_1` (roll) | RobStride 02 | 14 / 24 | `can9` / `can21` |
| `wrist_2` (pitch) | RobStride 00 | 15 / 25 | `can9` / `can21` |
| `wrist_3` (yaw) | RobStride 05 | 16 / 26 | `can9` / `can21` |

✅ **Check:** each actuator answers alone at its ID and carries its label.
{ .dh-check }

## Shoulder, elbow and wrist

<figure markdown>
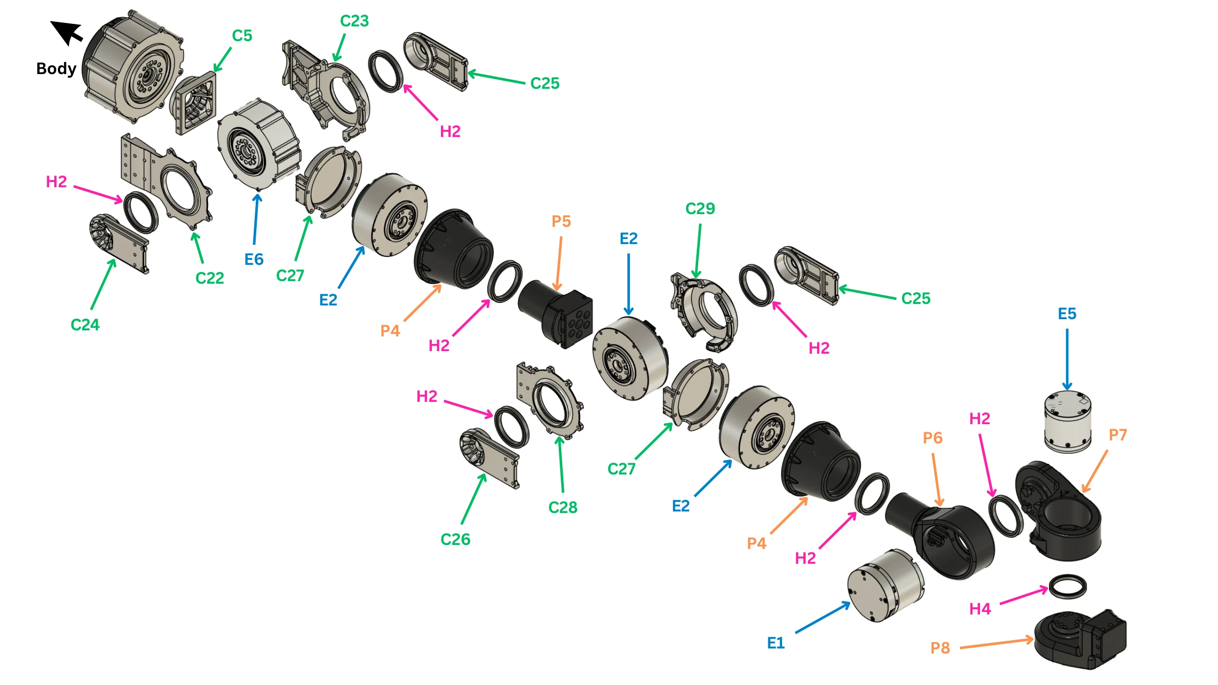
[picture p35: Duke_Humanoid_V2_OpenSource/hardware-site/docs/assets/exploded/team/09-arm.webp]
Right arm exploded, parts labelled with team BOM ids
  
  <figcaption>The right arm, body outward to the wrist: machined parts C5 and C22–C29, printed parts P4–P8, actuators E1, E2, E5 and E6, bearings H2 and H4. The unlabelled actuator at the top left, marked <em>Body</em>, is the shoulder-pitch actuator (E3), seated in the torso side plate.</figcaption>
</figure>

{{ booklet_parts("p.9") }}

<figure markdown>
  <video class="dh-clip" autoplay loop muted playsinline preload="metadata" width="1280" height="720"
    poster="../assets/exploded/arm-poster.webp" aria-label="Exploded view of one arm, shoulder-pitch actuator to wrist"><source src="../assets/exploded/arm.mp4" type="video/mp4"><a href="../assets/exploded/arm.mp4">MP4</a></video>
  <figcaption>Shoulder pitch to wrist. Shoulder roll and elbow each sit in a two-plate yoke, one bearing per plate. Click to pause; drag the bar to scrub.</figcaption>
</figure>

{{ step(2, "Build the shoulder-pitch joint") }}

The actuator (E3) sits in the torso side plate, output outward. Fit the output shaft (C5) on the output and the coupler (C27) over it: the arm hangs from this coupler.

✅ **Check:** turns freely, no axial play.
{ .dh-check }

{{ step(3, "Build the shoulder-roll joint") }}

Bolt the actuator (E6) into the bracket (C22). Fit the shoulder shaft (C24) on the output and the support shaft (C25) over the bearing (H2) in the retainer (C23). Make both sides concentric before tightening.

✅ **Check:** turns end to end, equal drag both ways, no axial play.
{ .dh-check }

{{ step(4, "Build the shoulder-yaw joint") }}

Fit the actuator (E2) with its shaft cover (P4) and bearing (H2).

✅ **Check:** the three shoulder joints move independently, nothing touches.
{ .dh-check }

{{ step(5, "Build the elbow joint") }}

Bolt the actuator (E2) into the bracket (C28). Fit the elbow shaft (C26) on the output through the coupler (P5) and cover (C27); fit the support shaft (C25) over the bearing (H2) in the retainer (C29).

✅ **Check:** no axial play; clears the upper arm at both ends of travel.
{ .dh-check }

{{ step(6, "Build the wrist-roll joint") }}

Fit the actuator (E2) with its shaft cover (P4); bolt the wrist shaft (P6) to the output.

✅ **Check:** turns freely, no axial play.
{ .dh-check }

{{ step(7, "Build the wrist-pitch joint") }}

Seat the actuator (E1) in the wrist housing (P7 on the right arm, P9 on the left) with its bearing (H4).

✅ **Check:** no binding; clears the wrist-roll body at both ends of travel.
{ .dh-check }

{{ step(8, "Build the wrist-yaw joint") }}

Fit the actuator (E5) and bolt the wrist output (P8) to it. The gripper bolts to this output.

✅ **Check:** the three wrist axes move together without contact.
{ .dh-check }

## Covers

<figure markdown>
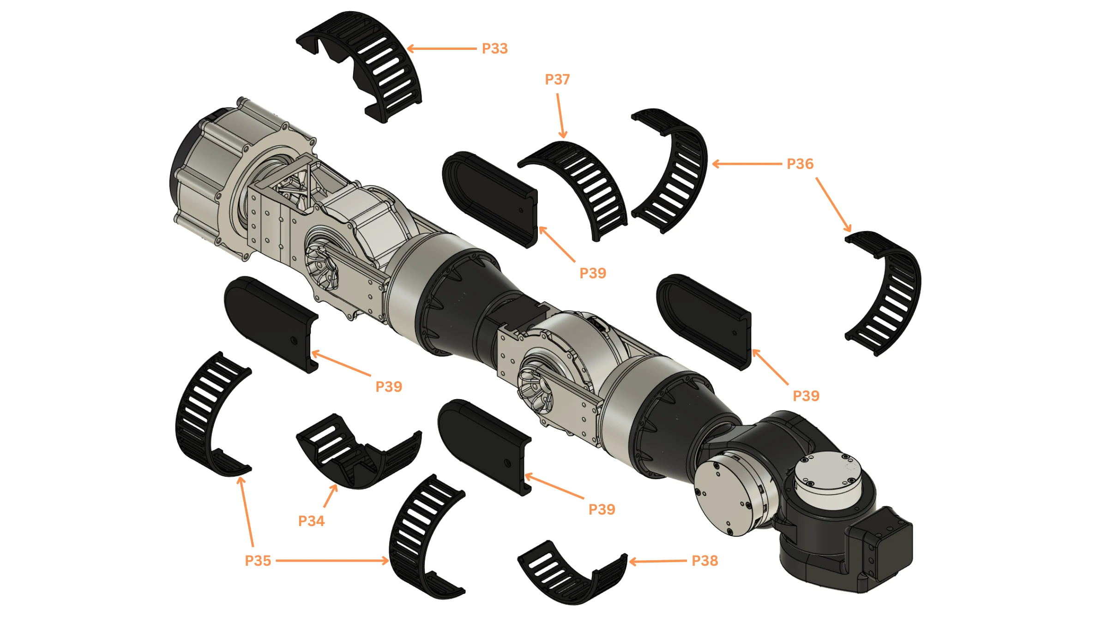
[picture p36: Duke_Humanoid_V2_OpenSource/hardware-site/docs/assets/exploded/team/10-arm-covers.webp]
Printed arm covers exploded, parts labelled with team BOM ids
  
  <figcaption>Printed TPU covers P33–P39, shoulder to wrist.</figcaption>
</figure>

{{ booklet_parts("p.10") }}

{{ step(9, "Route the harness and fit the covers") }}

Run three cable groups down the arm — `can22` to `shoulder_1`, the arm bus to the other six joints, and the gripper servo cable to the wrist — leaving the tails free at the shoulder for [Final integration](#final-integration); then fit the covers.

✅ **Check:** all seven joints move through their travel with no cable stretched or pinched; nothing rattles.
{ .dh-check }

## Build the second arm

<figure markdown>
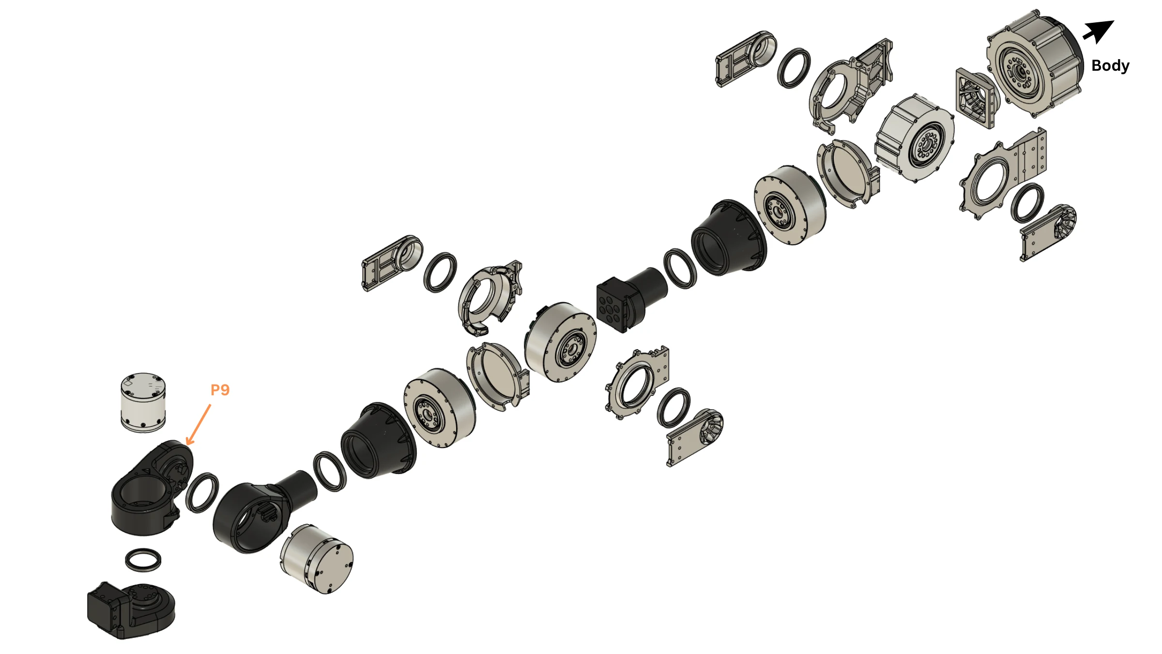
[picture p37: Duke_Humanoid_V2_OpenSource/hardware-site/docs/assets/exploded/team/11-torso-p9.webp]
Left arm exploded with the left wrist housing labelled
  
  <figcaption>The left arm: the same chain with the left wrist housing P9 in place of P7.</figcaption>
</figure>

{{ booklet_parts("p.11") }}

Repeat steps 2–9 with the left IDs, the left wrist housing (P9) and every A cover swapped with its B cover (P33/P34, P37/P38).

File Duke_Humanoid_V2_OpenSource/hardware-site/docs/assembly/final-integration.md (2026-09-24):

# Final integration

Join the subassemblies into one robot, battery disconnected throughout. Two people or a hoist from here on: lift by the top plate.

!!! abstract "At a glance"
    - **You will:** attach legs, arms, camera columns and grippers to the torso, join the harnesses, inspect and hang the robot.
    - **Before this:** [Gripper](#gripper); every actuator labelled with joint, ID and bus.

{{ step(1, "Support the torso") }}

Support it level, waist free, hips and shoulders reachable.

✅ **Check:** the torso cannot fall or rotate when a limb is offered up.
{ .dh-check }

{{ step(2, "Attach the legs") }}

Bolt each leg's hip-pitch bracket (C6) to the pelvis, supporting the leg's weight. Check the side: the legs differ by bus and IDs.

✅ **Check:** all twelve leg joints move; each harness tail reaches the torso, unconnected.
{ .dh-check }

{{ step(3, "Attach the arms") }}

Bolt each arm to its shoulder-pitch coupler (C27). Check the side: the arms differ by bus, IDs and wrist housing.

✅ **Check:** each arm moves through its travel without touching the torso or a leg.
{ .dh-check }

<figure markdown>
  <video class="dh-clip" autoplay loop muted playsinline preload="metadata" width="1154" height="650"
    poster="../assets/exploded/camera-mount-poster.webp" aria-label="Whole robot with camera columns and grippers lifting off"><source src="../assets/exploded/camera-mount.mp4" type="video/mp4"><a href="../assets/exploded/camera-mount.mp4">MP4</a></video>
  <figcaption>Camera columns onto the top plate; grippers onto the wrists. Click to pause; drag the bar to scrub.</figcaption>
</figure>

{{ step(4, "Mount the camera columns") }}

Bolt both columns to the top plate as in [Head and camera gimbal](#head-and-camera-gimbal), step 9.

✅ **Check:** yaw axes 130 mm apart; no column touches an arm in any pose.
{ .dh-check }

{{ step(5, "Mount the grippers") }}

Bolt each gripper to its wrist output (P8) as in [Gripper](#gripper), step 7; run the servo cable up the arm to its driver board.

✅ **Check:** both grippers work; their tags face the cameras in some arm pose.
{ .dh-check }

{{ step(6, "Join the harnesses") }}

Join one branch at a time against the bus table; wiring detail is on [Electrical](../electrical/index.md).

| Bus | Carries |
| --- | --- |
| `can22` | Waist (ID 1), both `shoulder_1` (10, 20) |
| `can9` / `can21` | Left / right arm, IDs 11–16 / 21–26 |
| `can24` / `can23` | Left / right leg, IDs 31–36 / 41–46 |
| `can25` | Camera gimbals, IDs 5–8 |

✅ **Check:** every branch is labelled; waist, hips and shoulders move with nothing pulled or pinched.
{ .dh-check }

{{ step(7, "Inspect and hang the robot") }}

Every joint moves by hand, alone and in combination; no cable is stretched, pinched or kinked in any pose; nothing rattles; lenses clean; packs disconnected. Hang the robot from the top plate with the legs straight.

✅ **Check:** it hangs level, legs straight.
{ .dh-check }

Next: [Electrical](../electrical/index.md), then [Bring-up](../bringup/index.md).

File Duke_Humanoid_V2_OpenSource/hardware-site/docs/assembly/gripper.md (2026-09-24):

# Gripper

A rack-and-pinion parallel gripper: one serial-bus servo drives both jaws through a pinion. Build two.

!!! abstract "At a glance"
    - **You will:** set the servo IDs, build the housing, racks and fingers, fit the tags, wire the servo.
    - **Before this:** [Head and camera gimbal](#head-and-camera-gimbal).

{{ step(1, "Set the two servo IDs") }}

Set each servo (E15) ID on its driver board (E10), one at a time; mark ID and hand on the servo, and record each board's USB serial against its hand.

| | Left | Right |
| --- | ---: | ---: |
| Servo ID | 5 | 19 |

✅ **Check:** each servo answers at its ID; hands and board serials recorded.
{ .dh-check }

<figure markdown>
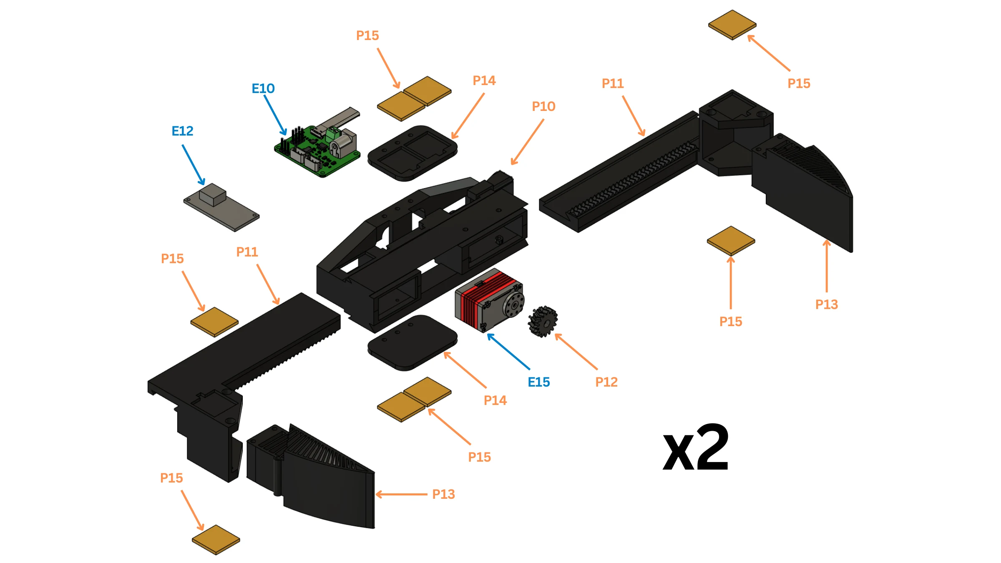
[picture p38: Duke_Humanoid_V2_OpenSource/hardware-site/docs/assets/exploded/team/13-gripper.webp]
One gripper exploded, parts labelled with team BOM ids
  
  <figcaption>One gripper (build two): housing P10, racks P11, pinion P12, fingers P13, AprilTag holders P14, tags P15, servo E15, driver board E10, buck converter E12.</figcaption>
</figure>

{{ booklet_parts("p.13") }}

{{ step(2, "Fit the servo and pinion into the housing") }}

Bolt the servo (E15) into the housing (P10) and the pinion (P12) onto its output.

✅ **Check:** the servo is fixed and turns the pinion with no lost motion.
{ .dh-check }

{{ step(3, "Fit both racks") }}

Slide the two racks (P11) into the housing from opposite sides, both engaged on the pinion, jaws symmetric about the centreline.

✅ **Check:** the jaws move together, parallel and symmetric, without binding.
{ .dh-check }

{{ step(4, "Fit the fingers") }}

Fit one finger (P13) to each rack.

✅ **Check:** the fingers meet flat when the jaws close.
{ .dh-check }

{{ step(5, "Fit the AprilTags") }}

Fit the two tag holders (P14) to the housing and seat the eight tag tiles (P15) square in their pockets, each with the tag ID the perception configuration assigns to that slot and hand.

✅ **Check:** all eight tags sit square and carry the right IDs.
{ .dh-check }

{{ step(6, "Wire the servo") }}

Wire the servo to its driver board (E10), fed 12 V by its buck converter (E12); the board plugs into a torso USB hub ([CAN bus](../electrical/index.md#can-bus)).

{{ step(7, "Mount the gripper on the wrist") }}

Bolt the housing to the wrist output (P8) with the jaws opening front-to-back at encoder zero; the control software checks this on every model rebuild.

✅ **Check:** the gripper is square to the wrist; the jaws open front-to-back.
{ .dh-check }

Open and closed positions are set at [Bring-up](../bringup/index.md).

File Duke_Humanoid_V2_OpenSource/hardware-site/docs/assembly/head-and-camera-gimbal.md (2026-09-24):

# Head and camera gimbal

Two identical camera columns: a RealSense D436 on a yaw–pitch gimbal of two RobStride 05.

!!! abstract "At a glance"
    - **You will:** build one column, repeat it, then bolt both to the top plate.
    - **Before this:** [Torso and waist](#torso-and-waist).

<figure markdown>
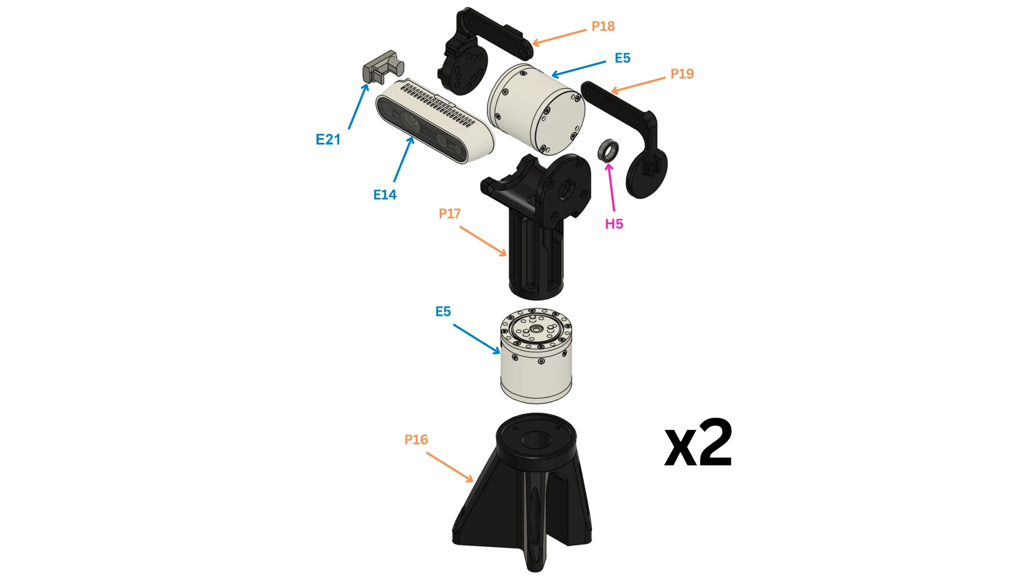
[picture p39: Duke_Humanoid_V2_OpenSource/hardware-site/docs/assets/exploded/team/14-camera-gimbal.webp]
One camera column exploded, parts labelled with team BOM ids
  
  <figcaption>One column (build two). Base P16, yaw actuator E5, neck P17, pitch actuator E5, arms P18 and P19, bearing H5, camera E14, USB-C adapter E21.</figcaption>
</figure>

{{ booklet_parts("p.14") }}

<figure markdown>
  <video class="dh-clip" autoplay loop muted playsinline preload="metadata" width="1280" height="720"
    poster="../assets/exploded/twincities-poster.webp" aria-label="Exploded view of one camera gimbal column"><source src="../assets/exploded/twincities.mp4" type="video/mp4"><a href="../assets/exploded/twincities.mp4">MP4</a></video>
  <figcaption>How the column comes together. Click to pause; drag the bar to scrub.</figcaption>
</figure>

{{ step(1, "Set the actuator IDs") }}

Set and label the four IDs on the bench, before anything is assembled.

| Joint | ID | Bus |
| --- | ---: | --- |
| `cam_yaw_left` | 7 | `can25` |
| `cam_pitch_left` | 8 | `can25` |
| `cam_yaw_right` | 5 | `can25` |
| `cam_pitch_right` | 6 | `can25` |

✅ **Check:** IDs 5 to 8 answer on `can25`.
{ .dh-check }

{{ step(2, "Fit the yaw actuator into the base") }}

Seat the yaw actuator (E5) in the base (P16), body on the yaw axis.

✅ **Check:** the output turns freely, no axial play.
{ .dh-check }

{{ step(3, "Fit the neck to the yaw output") }}

Bolt the neck (P17) to the yaw actuator output.

✅ **Check:** the neck turns square to the yaw axis, no wobble.
{ .dh-check }

{{ step(4, "Fit the pitch actuator into the neck") }}

Seat the pitch actuator (E5) in the neck (P17), its axis horizontal and crossing the yaw axis.

{{ step(5, "Fit the two arms") }}

Bolt the arm (P18) to the pitch actuator output. On the other side, press the bearing (H5) into the support arm (P19) and fit it over the neck's idler pin.

✅ **Check:** both arms swing together through the full pitch travel without binding.
{ .dh-check }

{{ step(6, "Mount the camera") }}

Fit the camera (E14) between the two arms and plug the right-angle USB-C adapter (E21) into it. Hold the camera by its body; leave the lens film on until the build is done.

✅ **Check:** the camera does not move under hand pressure.
{ .dh-check }

{{ step(7, "Route the camera cable") }}

Run the USB-A to USB-C cable (E9) from the adapter (E21) down the column and into the torso, with slack across the pitch and yaw axes and no tight bends: a flexed USB 3 cable drops the camera to USB 2. Fix it to the neck so it cannot snag anywhere in the yaw travel.

✅ **Check:** the camera streams USB 3 at every extreme of hand-turned travel.
{ .dh-check }

{{ step(8, "Build the second column") }}

Repeat steps 2–7 with the other side's IDs.

{{ step(9, "Mount both columns on the top plate") }}

Bolt each base flush on the top plate (`CNC_body03_top_plate`), through the concentric holes, yaw axes 130 mm apart. The right column is the left rotated 180°. `cam_yaw_left` (IDs 7/8) is the column on the robot's left.

✅ **Check:** yaw axes 130 mm apart; the columns never touch through full travel.
{ .dh-check }

{{ step(10, "Zero the joints") }}

Zero each joint with the camera looking straight out and level; the control code assumes encoder zero is that pose. Record the camera serial per side for [Camera calibration](../bringup/index.md#camera-calibration).

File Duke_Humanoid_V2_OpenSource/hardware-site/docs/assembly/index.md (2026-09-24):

# Assembly

Build the robot as bench subassemblies, in this order, then join them:

1. [Leg](#leg) ×2.
2. [Arm](#arm) ×2.
3. [Torso and waist](#torso-and-waist).
4. [Head and camera gimbal](#head-and-camera-gimbal): two camera columns.
5. [Gripper](#gripper) ×2.
6. [Final integration](#final-integration).

Then [Electrical](../electrical/index.md) and [Bring-up](../bringup/index.md).

<figure markdown>
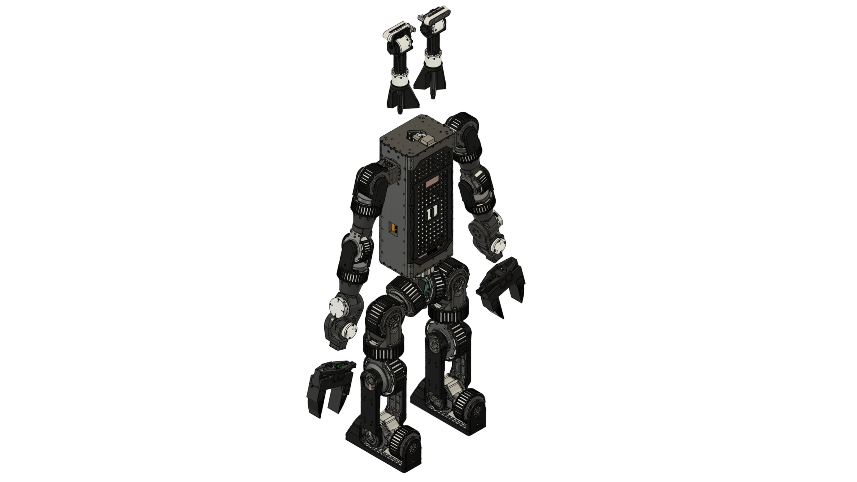
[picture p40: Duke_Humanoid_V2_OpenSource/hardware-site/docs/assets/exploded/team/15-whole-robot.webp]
The robot with both camera columns and both grippers lifted off
  
  <figcaption>Torso, legs and arms assembled; the two camera columns and two grippers lifted off.</figcaption>
</figure>

## Find a part on the robot

Every exploded view below is followed by its parts table. **Label** is the number drawn on the figure and the Team ref of the [Bill of materials](../bom/index.md); **Part ID** is the file name on [CAD downloads](../fabrication/index.md#cad-downloads). Click **Preview** in a row to see the part on the robot.

<div class="dh-viewer-block">
<model-viewer id="dh-viewer" data-base="../" src="../assets/viewer/robot.glb" camera-controls
  camera-orbit="35deg 75deg auto" min-camera-orbit="auto auto 0.3m" max-camera-orbit="auto auto 6m"
  interaction-prompt="none" shadow-intensity="0.6" exposure="1.1" loading="eager"
  alt="Duke Humanoid V2, every component in its Fusion 360 appearance">
  <button slot="hotspot-x" class="dh-axis dh-axis-x" type="button" tabindex="-1" data-position="0m 0m 0m" aria-label="X axis">X</button>
  <button slot="hotspot-y" class="dh-axis dh-axis-y" type="button" tabindex="-1" data-position="0m 0m 0m" aria-label="Y axis">Y</button>
  <button slot="hotspot-z" class="dh-axis dh-axis-z" type="button" tabindex="-1" data-position="0m 0m 0m" aria-label="Z axis">Z</button>
</model-viewer>
<div class="dh-viewer-bar">
  <button id="dh-viewer-reset" class="md-button" type="button">Show all</button>
  <span class="dh-viewer-legend"><span>Colours are the Fusion appearances</span><span><i class="dh-sw-amber"></i>hovered row</span><span><i class="dh-sw-red"></i>selected on the model</span><span><i class="dh-sw-blue"></i>selected row</span></span>
  
</div>
<p class="dh-viewer-note">Axes are the STEP file axes (right-handed, Z up).</p>
</div>

{{ step_ns("leg") }}
{% include "assembly/leg.md" %}

{{ step_ns("arm") }}
{% include "assembly/arm.md" %}

{{ step_ns("torso-and-waist") }}
{% include "assembly/torso-and-waist.md" %}

{{ step_ns("head-and-camera-gimbal") }}
{% include "assembly/head-and-camera-gimbal.md" %}

{{ step_ns("gripper") }}
{% include "assembly/gripper.md" %}

{{ step_ns("final-integration") }}
{% include "assembly/final-integration.md" %}

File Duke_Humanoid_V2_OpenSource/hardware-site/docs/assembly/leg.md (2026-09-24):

# Leg

One leg, hip to foot: six RobStride joints in a chain of machined brackets and shafts. Build two; the second is the mirror of the first.

!!! abstract "At a glance"
    - **You will:** set six IDs, build the hip (three joints), then the knee, shank, ankle and foot, then fit the covers.
    - **Before this:** nothing; the leg is the first subassembly.

{{ step(1, "Set the six actuator IDs") }}

Set and label each ID on the bench, one actuator at a time. All six joints of a leg share one CAN bus.

| Joint | Actuator | ID left / right | Bus left / right |
| --- | --- | --- | --- |
| `hip_1` (pitch) | RobStride 03 | 31 / 41 | `can24` / `can23` |
| `hip_2` (roll) | RobStride 03 | 32 / 42 | `can24` / `can23` |
| `hip_3` (yaw) | RobStride 03 | 33 / 43 | `can24` / `can23` |
| `knee` | RobStride 04 | 34 / 44 | `can24` / `can23` |
| `ankle_1` (pitch) | RobStride 03 | 35 / 45 | `can24` / `can23` |
| `ankle_2` (roll) | RobStride 06 | 36 / 46 | `can24` / `can23` |

✅ **Check:** each actuator answers alone at its ID and carries its label.
{ .dh-check }

## Hip

<figure markdown>
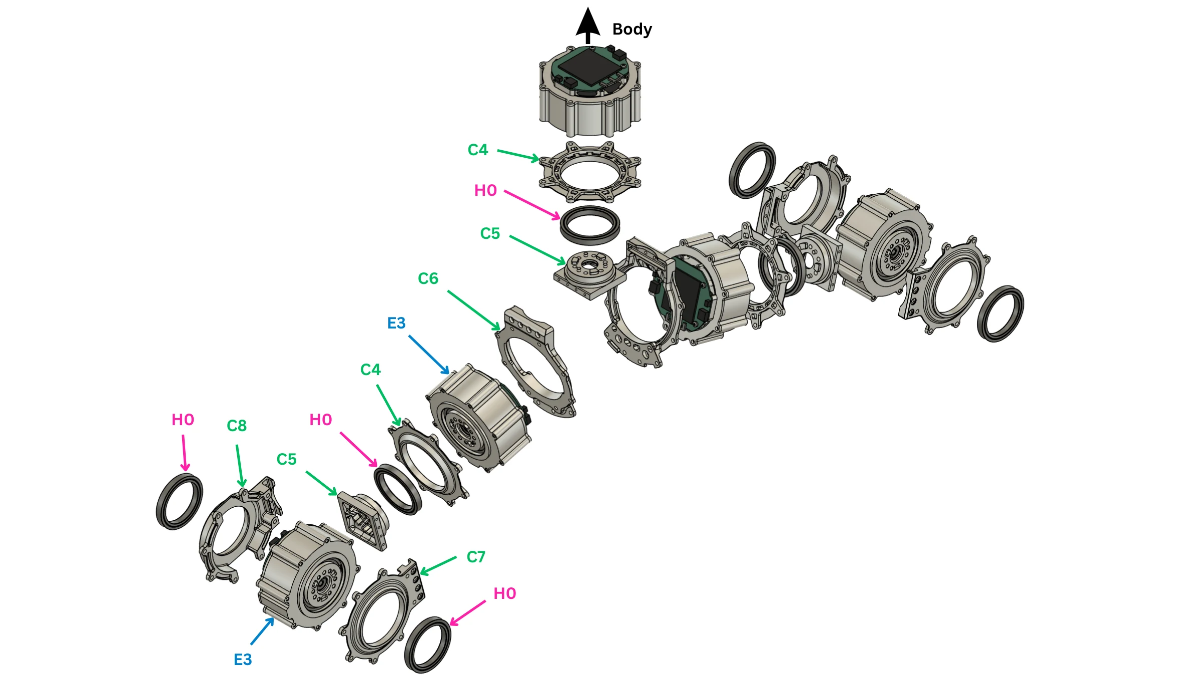
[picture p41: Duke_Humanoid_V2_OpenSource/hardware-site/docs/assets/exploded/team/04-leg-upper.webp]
Hip pitch and roll exploded, parts labelled with team BOM ids
  
  <figcaption>Hip pitch and hip roll, body outward: brackets and retainers C4–C8, actuators E3, bearings H0. The unlabelled actuator at the top, marked <em>Body</em>, is the waist actuator (E3) of the torso.</figcaption>
</figure>

{{ booklet_parts("p.4") }}

<figure markdown>
  <video class="dh-clip" autoplay loop muted playsinline preload="metadata" width="1280" height="720"
    poster="../assets/exploded/hip-assembly-poster.webp" aria-label="Exploded view of the pelvis block with the waist and four hip actuators"><source src="../assets/exploded/hip-assembly.mp4" type="video/mp4"><a href="../assets/exploded/hip-assembly.mp4">MP4</a></video>
  <figcaption>The pelvis block: waist actuator in the middle, hip pitch and hip roll on each side. Click to pause; drag the bar to scrub.</figcaption>
</figure>

{{ step(2, "Build the hip-pitch joint") }}

Bolt the actuator (E3) into the bracket (C6). Fit the output shaft (C5) on the output and the bearing (H0) in its retainer (C4) on the far side.

✅ **Check:** turns freely, even drag, no axial play.
{ .dh-check }

{{ step(3, "Build the hip-roll joint") }}

Bolt the actuator (E3) into the front bracket (C7). Fit the output shaft (C5) on the output; seat the bearing (H0) in the back retainer (C8). Make both retainers concentric before tightening.

✅ **Check:** turns end to end without binding, equal drag both ways, no axial play.
{ .dh-check }

## Knee, shank, ankle and foot

<figure markdown>
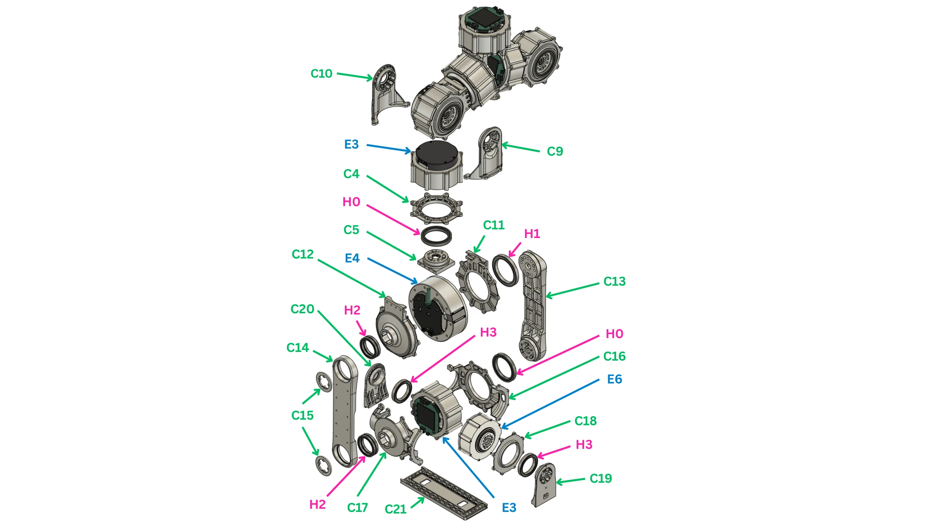
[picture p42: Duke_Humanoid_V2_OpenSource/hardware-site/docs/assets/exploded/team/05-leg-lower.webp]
Hip yaw to foot plate exploded, parts labelled with team BOM ids
  
  <figcaption>Hip yaw down to the foot: machined parts C4, C5 and C9–C21, actuators E3, E4 and E6, bearings H0–H3.</figcaption>
</figure>

{{ booklet_parts("p.5") }}

<figure markdown>
  <video class="dh-clip" autoplay loop muted playsinline preload="metadata" width="1280" height="720"
    poster="../assets/exploded/leg-poster.webp" aria-label="Exploded view of one leg hanging from the pelvis block"><source src="../assets/exploded/leg.mp4" type="video/mp4"><a href="../assets/exploded/leg.mp4">MP4</a></video>
  <figcaption>The leg below the pelvis: hip yaw, knee, the two shank links, ankle pitch, ankle roll, foot. Click to pause; drag the bar to scrub.</figcaption>
</figure>

{{ step(4, "Build the hip-yaw joint") }}

Fit the output shaft (C9) on the actuator (E3) output and the support shaft (C10) over the bearing on the other side; the output shaft (C5) and retainer (C4) sit on the actuator as in step 2.

✅ **Check:** the three hip joints move independently, nothing touches.
{ .dh-check }

{{ step(5, "Build the knee joint") }}

Bolt the actuator (E4) into the bracket (C11); fit the bearing retainer (C12) with its bearing on the back.

✅ **Check:** turns freely, no axial play; the retainer sits without a gap.
{ .dh-check }

{{ step(6, "Join the shank to the knee") }}

Bolt the shank shaft (C13) to the knee output and the shank support (C14) to the far side; close each shank joint with a cap (C15).

✅ **Check:** the knee still turns freely.
{ .dh-check }

{{ step(7, "Build the ankle-pitch joint") }}

Bolt the actuator (E3) into the bracket (C16); fit the output shaft (C5), the retainer (C4) with its bearing, and the back retainer (C17).

✅ **Check:** no axial play; clears the shank at both ends of travel.
{ .dh-check }

{{ step(8, "Build the ankle-roll joint") }}

Bolt the actuator (E6) with its retainer (C18); fit the foot shaft (C19) on the output and the foot support (C20) over the bearing on the other side. Make both shaft ends concentric before tightening.

✅ **Check:** no axial play; pitch and roll never collide.
{ .dh-check }

{{ step(9, "Fit the foot") }}

Bolt the foot (C21) to the foot shaft and support.

✅ **Check:** at ankle zero the foot sits flat.
{ .dh-check }

## Covers

<figure markdown>
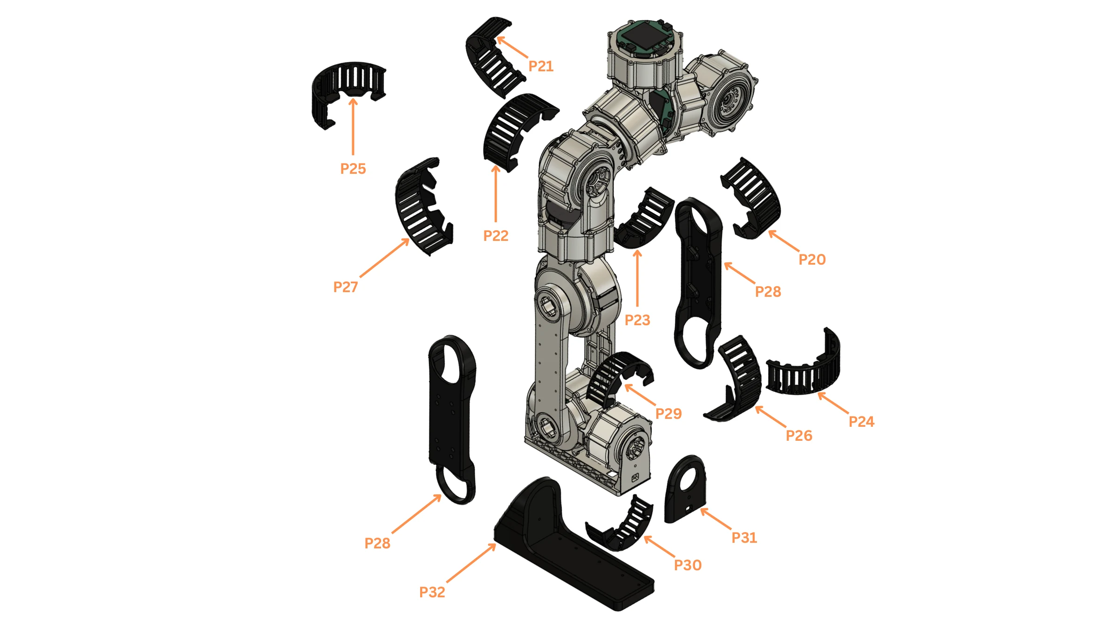
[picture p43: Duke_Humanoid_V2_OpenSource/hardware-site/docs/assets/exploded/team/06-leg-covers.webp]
Printed leg covers exploded, parts labelled with team BOM ids
  
  <figcaption>Printed TPU covers P20–P32, hip to sole.</figcaption>
</figure>

{{ booklet_parts("p.6") }}

{{ step(10, "Route the harness and fit the covers") }}

Run the leg's CAN chain and power branch from the foot up to the hip, leaving the tail free at the hip for [Final integration](#final-integration); then fit the covers, sole (P32) and foot front (P31).

✅ **Check:** all six joints move through their travel with no cable stretched or pinched; nothing rattles.
{ .dh-check }

## Build the second leg

Repeat steps 2–10. The legs are mirrors: every A cover swaps with its B cover (P20/P21, P22/P23, P24/P25, P26/P27, P29/P30).

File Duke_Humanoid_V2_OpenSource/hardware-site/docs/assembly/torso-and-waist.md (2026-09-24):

# Torso and waist

The torso: a machined plate frame carrying the waist actuator, both shoulder-pitch actuators, the electronics and the battery packs, closed by printed covers.

!!! abstract "At a glance"
    - **You will:** build the frame, seat the three actuators, mount the electronics and packs, fit the covers.
    - **Before this:** [Arm](#arm).

{{ step(1, "Set the waist actuator ID") }}

| Joint | Actuator | ID | Bus |
| --- | --- | ---: | --- |
| `waist` | RobStride 03 | 1 | `can22` (shared with both `shoulder_1`) |

✅ **Check:** answers at ID 1; labelled.
{ .dh-check }

## Frame

<figure markdown>
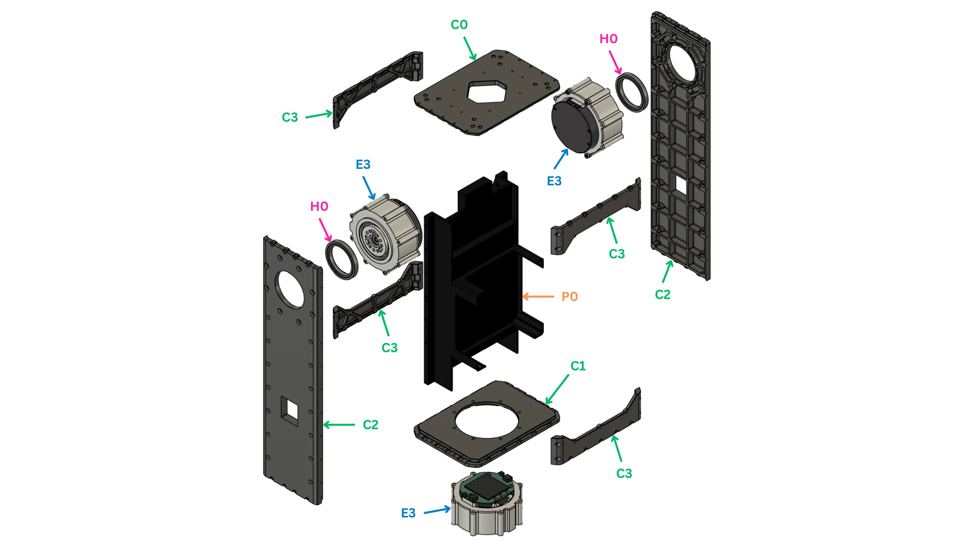
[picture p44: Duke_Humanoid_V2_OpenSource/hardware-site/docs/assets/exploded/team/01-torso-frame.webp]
Torso frame exploded, parts labelled with team BOM ids
  
  <figcaption>The frame: plates C0–C3, interior plate P0, actuators E3, bearings H0.</figcaption>
</figure>

{{ booklet_parts("p.1") }}

<figure markdown>
  <video class="dh-clip" autoplay loop muted playsinline preload="metadata" width="1280" height="720"
    poster="../assets/exploded/body-frame-poster.webp" aria-label="Exploded view of the torso plate frame"><source src="../assets/exploded/body-frame.mp4" type="video/mp4"><a href="../assets/exploded/body-frame.mp4">MP4</a></video>
  <figcaption>Plates, interior plate, both shoulder-pitch actuators and the waist actuator. Click to pause; drag the bar to scrub.</figcaption>
</figure>

{{ step(2, "Assemble the plate frame") }}

Bolt the two side plates (C2) and the four front/back plates (C3) to the bottom plate (C1); fit the interior plate (P0). Square the frame before anything goes in: every limb and camera references it.

✅ **Check:** flat on a surface plate, square, no racking when pushed.
{ .dh-check }

{{ step(3, "Seat the waist actuator") }}

Seat the actuator (E3) in the bottom plate's round opening, driver board up, output down into the pelvis, with its output shaft (C5), retainer (C4) and bearing (H0) as on the hip joints.

✅ **Check:** turns freely, no axial play; square to the pelvis at zero.
{ .dh-check }

{{ step(4, "Seat the shoulder-pitch actuators and fit the top plate") }}

Seat one shoulder-pitch actuator (E3) in each side plate, output outward, with its bearing (H0). Bolt the top plate (C0) on last: it is the datum for both camera columns.

✅ **Check:** flat and square to the frame; both shoulder outputs turn freely.
{ .dh-check }

## Electronics and packs

<figure markdown>
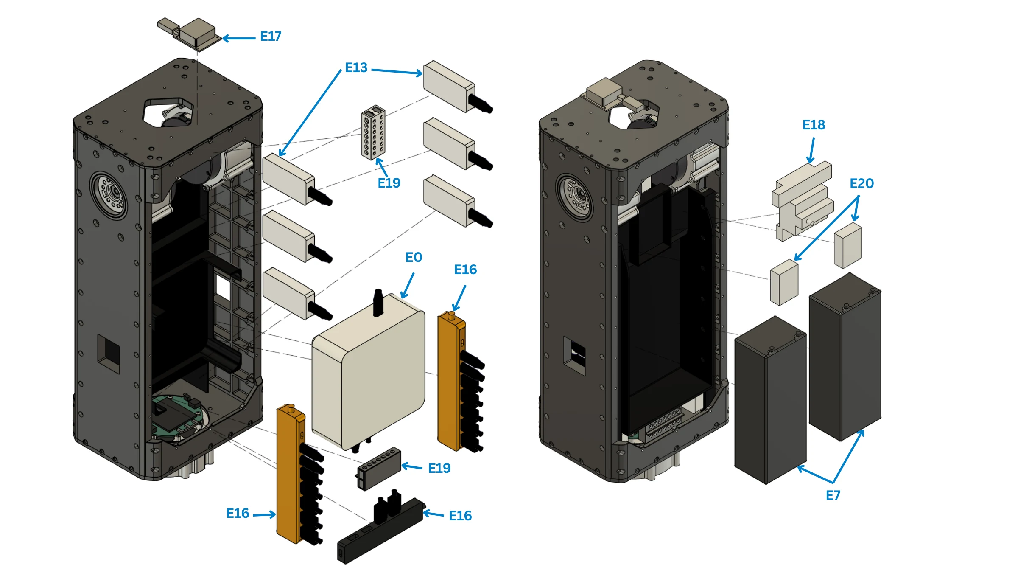
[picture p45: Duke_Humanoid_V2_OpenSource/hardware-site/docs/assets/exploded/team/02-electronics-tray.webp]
Torso electronics exploded, parts labelled with team BOM ids
  
  <figcaption>Computer E0 on the interior plate; packs E7; CAN adapters E13, hubs E16, IMU E17, surge protector E18, distribution blocks E19, voltage checkers E20.</figcaption>
</figure>

{{ booklet_parts("p.2") }}

<figure markdown>
  <video class="dh-clip" autoplay loop muted playsinline preload="metadata" width="1280" height="720"
    poster="../assets/exploded/body-front-poster.webp" aria-label="Exploded view of the torso front electronics bay"><source src="../assets/exploded/body-front.mp4" type="video/mp4"><a href="../assets/exploded/body-front.mp4">MP4</a></video>
  <figcaption>Front bay: CAN adapters, the computer on the interior plate, distribution blocks. Click to pause; drag the bar to scrub.</figcaption>
</figure>

<figure markdown>
  <video class="dh-clip" autoplay loop muted playsinline preload="metadata" width="1280" height="720"
    poster="../assets/exploded/body-back-poster.webp" aria-label="Exploded view of the torso rear bay with two upright packs"><source src="../assets/exploded/body-back.mp4" type="video/mp4"><a href="../assets/exploded/body-back.mp4">MP4</a></video>
  <figcaption>Rear bay: the two packs upright behind the interior plate. Click to pause; drag the bar to scrub.</figcaption>
</figure>

{{ step(5, "Mount the computer") }}

Bolt the computer (E0) to the interior plate above the waist, intake, exhaust and ports clear.

{{ step(6, "Mount the CAN adapters, hubs and power parts") }}

Mount the six CAN adapters (E13), three USB hubs (E16), surge protector (E18), four distribution blocks (E19) and two voltage checkers (E20) in the front bay. Label each CAN adapter with its bus before wiring; wire per [Power system](../electrical/index.md#power-system) and [CAN bus](../electrical/index.md#can-bus).

✅ **Check:** every adapter carries its bus label; no board hangs on its cable.
{ .dh-check }

{{ step(7, "Mount the IMU") }}

Bolt the IMU (E17) rigidly, its axes parallel to the robot base frame: the control software applies no mounting rotation.

✅ **Check:** rigid; axes checked against the frame.
{ .dh-check }

{{ step(8, "Fit the battery packs") }}

Stand the two packs (E7) upright, side by side, in the rear bay. Leave both disconnected until [Pre-power checks](../electrical/index.md#pre-power-checks) pass.

✅ **Check:** packs cannot shift; no lead is taut or on an edge; each pack comes out.
{ .dh-check }

## Covers

<figure markdown>
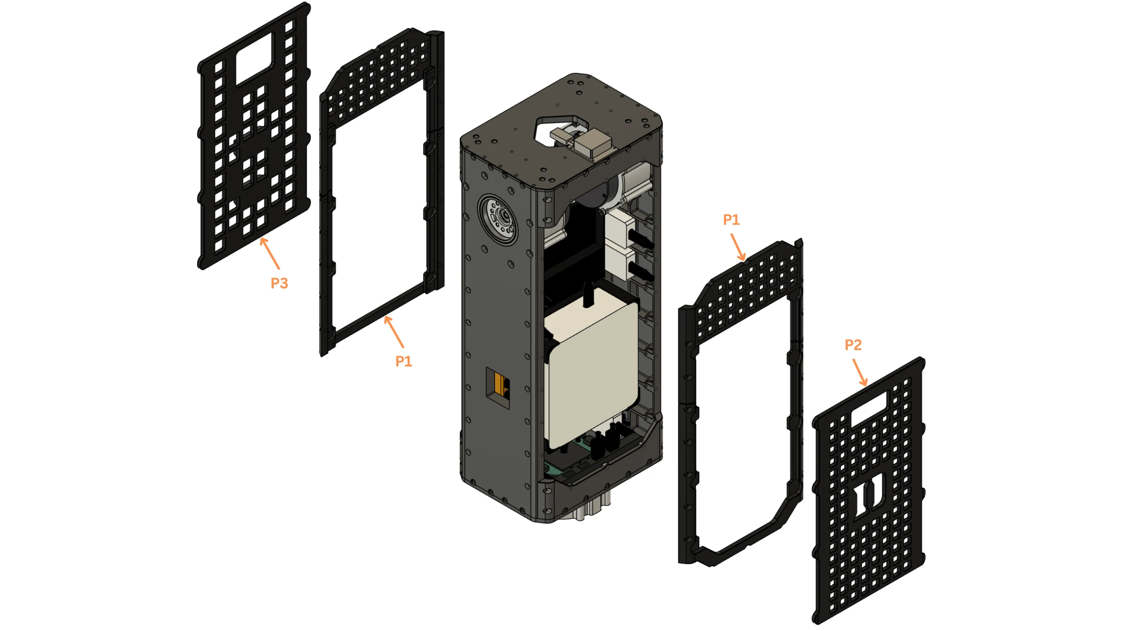
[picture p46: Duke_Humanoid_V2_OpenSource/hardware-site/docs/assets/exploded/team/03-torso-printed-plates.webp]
Torso printed plates exploded, parts labelled with team BOM ids
  
  <figcaption>Printed covers P1, front plate P2, back plate P3.</figcaption>
</figure>

{{ booklet_parts("p.3") }}

<figure markdown>
  <video class="dh-clip" autoplay loop muted playsinline preload="metadata" width="1248" height="702"
    poster="../assets/exploded/body-cover-poster.webp" aria-label="Exploded view of the torso front and back covers"><source src="../assets/exploded/body-cover.mp4" type="video/mp4"><a href="../assets/exploded/body-cover.mp4">MP4</a></video>
  <figcaption>Front and back covers: each a perforated frame plus a removable panel. Click to pause; drag the bar to scrub.</figcaption>
</figure>

{{ step(9, "Fit the covers") }}

Fit the two covers (P1) front and back, then the removable front plate (P2) and back plate (P3).

✅ **Check:** nothing inside moves when the torso is tilted; the waist still turns.
{ .dh-check }

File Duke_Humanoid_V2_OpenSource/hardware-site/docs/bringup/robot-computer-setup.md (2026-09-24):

# Robot computer setup

Once, before any bus is touched. Ubuntu 22.04 on the MINISFORUM X1-470.

| Item | Do |
| --- | --- |
| CAN adapters | Flash each CANable PRO V2.0 with candleLight (ElmueSoft [CANable Firmware Update](https://netcult.ch/elmue/CANable%20Firmware%20Update/), button held for flash mode, adapter plugged straight into the computer) |
| Host | `sudo apt remove brltty`; `sudo adduser $USER netdev dialout`; `sudo apt install can-utils libsocketcan-dev`; log out and in |
| Bus names | One udev rule per adapter serial, below; then `sudo udevadm control --reload-rules && sudo udevadm trigger` and replug |
| IMU | TransducerM TM171 in the vendor's ImuAssistant: output Composite + Status, 800 Hz, USB port, gyro / accelerometer / magnetometer on, GyroErrFilter and self-adapt filter on |
| Cameras | librealsense2 **2.58.1** (`librealsense2 -utils -dev -gl -udev-rules`) from `librealsense.realsenseai.com`; deploy pins `pyrealsense2==2.58.1.10581` |
| Control stack | Build `deploy/control` with the CMake + vcpkg + Ninja presets |

```text
# /etc/udev/rules.d/99-candlelight.rules — one line per adapter, serial from `sudo dmesg`
SUBSYSTEM=="net", ACTION=="add", ATTRS{serial}=="<serial>", NAME="can9"     # left arm
SUBSYSTEM=="net", ACTION=="add", ATTRS{serial}=="<serial>", NAME="can21"    # right arm
SUBSYSTEM=="net", ACTION=="add", ATTRS{serial}=="<serial>", NAME="can22"    # waist, shoulder_1
SUBSYSTEM=="net", ACTION=="add", ATTRS{serial}=="<serial>", NAME="can23"    # right leg
SUBSYSTEM=="net", ACTION=="add", ATTRS{serial}=="<serial>", NAME="can24"    # left leg
SUBSYSTEM=="net", ACTION=="add", ATTRS{serial}=="<serial>", NAME="can25"    # camera gimbals
SUBSYSTEM=="net", KERNEL=="can[0-9]*", GROUP="can", MODE="0660"
```

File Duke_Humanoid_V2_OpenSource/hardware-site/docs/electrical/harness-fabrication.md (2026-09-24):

# Harness fabrication

Every cable on the robot is one of the types below. Red is +, black is −; CAN_H is yellow and CAN_L is blue throughout the harness. Solder the XT30 cups (iron about 480 °C), do not crimp them; never mate or unmate a power connector under power.

| Cable | Conductors | End A | End B | Carries |
| --- | --- | --- | --- | --- |
| Actuator drop | 2 × 18 AWG power + 1 twisted pair CAN | XT30(2+2) female, cable side (Amass XT30(2+2)-F.G.B) | XT30(2+2) female | 48 V and CAN in one shell: pin 1 +, pin 2 −, pin 3 CAN_L, pin 4 CAN_H. Every actuator has an in and an out socket (board side XT30PB(2+2)-M.G.B), so the drops chain motor to motor |
| Bus head | 1 twisted pair | CANable PRO screw terminals, 120 Ω across H–L | XT30(2+2) female, power pins unused | CAN only, adapter to the first motor |
| Bus tail terminator | — | 120 Ω resistor across CAN_H–CAN_L in an XT30(2+2) shell | — | Plugs into the last motor's out socket |
| CAN twisted pair | One pair from Ethernet cable | — | — | Coloured conductor → CAN_H (yellow lead), white → CAN_L (blue lead); 3/32 in heat-shrink per lead, 1/4 in over the pair |
| Pack lead and series link | 10 AWG silicone | EC5 | EC5 / screw terminal | 48 V trunk |
| Block feeds | 12 AWG silicone | Screw terminal | Screw terminal | 48 V bus to each power block; pack − to each ground block |
| Computer feed | 16 AWG silicone | Converter (E11) 12 V terminals | Computer DC plug | 12 V; 10 A inline fuse on the 48 V side |
| Gripper servo feed | 18 AWG silicone | Converter (E12) 12 V terminals | Servo driver board (E10) terminals | 12 V, one per gripper |
| Camera USB | Belkin USB-A to USB-C (E9) | Computer / hub 1 | Right-angle USB-C adapter (E21) on the camera | USB 3 (5 Gbit/s) |
| Gripper servo signal | Servo's own lead | Servo (E15) | Driver board (E10) | Serial bus |

## Connectors and consumables

| Item | Part | Where |
| --- | --- | --- |
| Actuator connector, cable side | Amass XT30(2+2)-F.G.B (female, 4-pin: 2 power + 2 signal) | Both ends of every actuator drop, bus head, terminator |
| Actuator connector, board side | Amass XT30PB(2+2)-M.G.B (male, PCB mount) | Already on every RobStride board, in and out |
| Pack connector | EC5 | Pack leads, series link |
| Bus terminator | 120 Ω resistor | Adapter end and last motor of each bus |
| CAN pair | One twisted pair from Ethernet cable | All CAN runs |
| Power wire | Silicone, 12 / 16 / 18 AWG | Trunks / computer / actuator drops and grippers |
| Heat-shrink | 3/32 in per lead, 1/4 in over a pair or joint | Every solder joint |
| Loom | 1/4 in and 3/8 in | Limb runs |

XT30(2+2) is rated 15 A with 18 AWG wire. Quantities are yours to size: [Cables and connectors](../bom/index.md#cables-and-connectors).

✅ **Check:** each finished cable conducts pin to pin, has no short between pins, and is labelled at both ends with its bus or rail.
{ .dh-check }

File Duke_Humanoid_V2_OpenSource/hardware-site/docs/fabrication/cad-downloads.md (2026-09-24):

# CAD downloads

Download the whole robot, one module, or one part. Part files are named `<part_id>_rev<NN>`, matching the parts lists; left and right parts are separate files.

## Find a part on the robot

<div class="dh-viewer-block">
<model-viewer id="dh-viewer" data-base="../" src="../assets/viewer/robot.glb" camera-controls
  camera-orbit="35deg 75deg auto" min-camera-orbit="auto auto 0.3m" max-camera-orbit="auto auto 6m"
  interaction-prompt="none" shadow-intensity="0.6" exposure="1.1" loading="eager"
  alt="Duke Humanoid V2, every component in its Fusion 360 appearance">
  <button slot="hotspot-x" class="dh-axis dh-axis-x" type="button" tabindex="-1" data-position="0m 0m 0m" aria-label="X axis">X</button>
  <button slot="hotspot-y" class="dh-axis dh-axis-y" type="button" tabindex="-1" data-position="0m 0m 0m" aria-label="Y axis">Y</button>
  <button slot="hotspot-z" class="dh-axis dh-axis-z" type="button" tabindex="-1" data-position="0m 0m 0m" aria-label="Z axis">Z</button>
</model-viewer>
<div class="dh-viewer-bar">
  <button id="dh-viewer-reset" class="md-button" type="button">Show all</button>
  <span class="dh-viewer-legend"><span>Colours are the Fusion appearances</span><span><i class="dh-sw-amber"></i>hovered row</span><span><i class="dh-sw-red"></i>selected on the model</span><span><i class="dh-sw-blue"></i>selected row</span></span>
  
</div>
<p class="dh-viewer-note">Axes are the STEP file axes (right-handed, Z up).</p>
</div>

Click **Preview** in a row to see a part on the robot; click a component on the robot to jump to its row. **Hide selected** removes the selected part from view; **Show all** resets.

## Files

### Whole robot

Assembly STEP (zipped: over GitHub's file-size limit) and the Fusion 360 archive for editing. All STEP files are AP214, written by Fusion 360 from the `humanoid_2.1_latest` design.

{{ cad_table("assembly") }}

| File | Size | SHA-256 |
| --- | ---: | --- |
| [humanoid_2.1_latest.f3z](https://github.com/generalroboticslab/Duke_Humanoid_V2_OpenSource/releases/download/cad-v2.1-rc1/humanoid_2.1_latest.f3z) (101 linked designs included, release `cad-v2.1-rc1`) | 319 MB | `f440621df68f0775f521c87d02f8a644ae0a65f64ef76b385fdd2bc22a04d420` |

### Modules

One STEP per sub-assembly, parts assembled, in the sub-assembly's own coordinates. Depth 0 is directly under the robot.

??? note "Module files ({{ cad_count("modules") }})"
    {{ cad_table_modules() | indent(4) }}

### Parts

One file per component, in the component's own coordinates.

??? note "Machined and printed parts — STEP ({{ cad_count("step") }})"
    {{ cad_table("step") | indent(4) }}

??? note "Printable meshes — STL ({{ cad_count("print") }}); units are millimetres"
    {{ cad_table("print") | indent(4) }}

??? note "Purchased parts — vendor STEP ({{ cad_count("vendor") }}); for fit checks only, buy the parts"
    {{ cad_table("vendor", "Component") | indent(4) }}

### Drawings

The overall-dimension drawing and the exploded-view booklet, whose part labels are the team BOM ids used in the parts lists and on [Assembly](../assembly/index.md). There are no per-part drawings: machined parts are ordered from the STEP files.

{{ cad_table("drawings") }}

Everything ships under [Apache-2.0](https://www.apache.org/licenses/LICENSE-2.0) ([`LICENSE`](../files/LICENSE){ download="" }).

Checksums: [SHA256SUMS.txt](../files/SHA256SUMS.txt){ download="" } (`shasum -a 256 <file>`).

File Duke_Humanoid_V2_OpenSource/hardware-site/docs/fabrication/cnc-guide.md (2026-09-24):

# CNC guide

Order the machined parts from the STEP files; there are no per-part drawings.

| | |
| --- | --- |
| Material | Aluminium 6061 |
| Tolerance | 0.03 mm on radius and length, 0.06 mm on diameter |

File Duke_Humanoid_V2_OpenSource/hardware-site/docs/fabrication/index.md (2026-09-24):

# Fabrication

Turn the CAD into parts: download the files, order the machined parts, print the rest.

| | |
| --- | --- |
| Machining | {{ bom_count("cnc-parts.csv") }} parts in aluminium 6061, ordered from the STEP files |
| Printing | FDM in PLA and TPU; six SLS nylon 12 drivetrain parts from a print service |

{% include "fabrication/cad-downloads.md" %}

{% include "fabrication/cnc-guide.md" %}

{% include "fabrication/printing-guide.md" %}

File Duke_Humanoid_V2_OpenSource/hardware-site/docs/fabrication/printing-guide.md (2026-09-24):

# Printing guide

| Process | Parts | Material |
| --- | --- | --- |
| FDM | 40 covers, mounts, plates and pads | PLA; TPU for the pads and covers |
| SLS | The drivetrain parts below — each transmits actuator torque or carries a bearing | Nylon 12 |

| SLS part | Qty |
| --- | ---: |
| `3DP_arm05_RS02_shaft_bearing_retainer` | 4 |
| `3DP_arm06_RS02_shaft_coupler` | 2 |
| `3DP_arm11_wrist_roll` | 2 |
| `3DP_arm14_wrist_block` | 2 |
| `3DP_arm15_end_effector_attachment` | 2 |
| `3DP_grip05_pinion` | 2 |

Process and material per part: [Printed parts](../bom/index.md#printed-parts). Files: [CAD downloads](#cad-downloads).

FDM holes print undersize: ream them to size. Set heat-set inserts with a soldering iron.

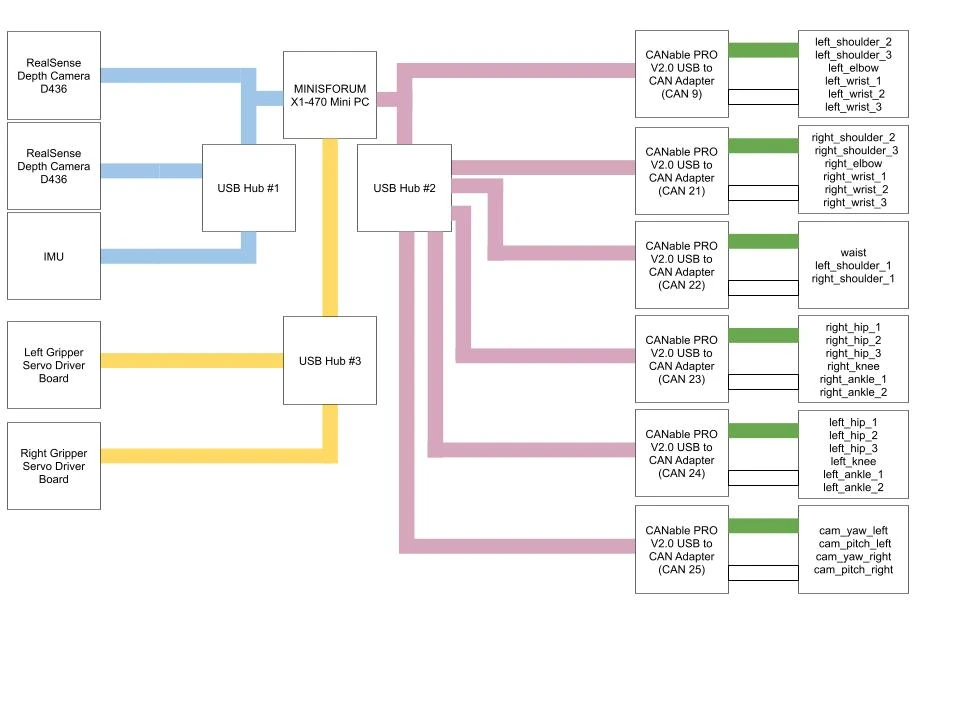
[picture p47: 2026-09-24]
Duke_Humanoid_V2_OpenSource/hardware-site/docs/assets/wiring/data-wiring-v2.webp

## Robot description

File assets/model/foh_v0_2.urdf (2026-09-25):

<?xml version="1.0"?>
<robot name="foh_v0_2">
  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
  <mujoco><compiler discardvisual="false" balanceinertia="true"/></mujoco>
  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
  <link name="pelvis">
    <inertial><origin xyz="0.00000 0.00000 0.48802" rpy="0 0 0"/><mass value="3.4050"/>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</inertial>
    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
  </link>
  <link name="torso">
    <inertial><origin xyz="-0.00897 -0.00075 0.22103" rpy="0 0 0"/><mass value="6.6250"/>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</inertial>
    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
  </link>
  <link name="hip_roll_bracket_L">
    <inertial><origin xyz="0.00200 0.05580 0.00012" rpy="0 0 0"/><mass value="1.0710"/>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</inertial>
    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
  </link>
  <link name="hip_yaw_housing_L">
    <inertial><origin xyz="-0.03903 0.00045 -0.08721" rpy="0 0 0"/><mass value="1.1970"/>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</inertial>
    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
  </link>
  <link name="thigh_L">
    <inertial><origin xyz="0.00000 0.00733 -0.05914" rpy="0 0 0"/><mass value="1.1430"/>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</inertial>
    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
  </link>
  <link name="shank_L">
    <inertial><origin xyz="0.00000 -0.02692 -0.14308" rpy="0 0 0"/><mass value="1.2320"/>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</inertial>
    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
  </link>
  <link name="ankle_block_L">
    <inertial><origin xyz="-0.09598 -0.04366 -0.02592" rpy="0 0 0"/><mass value="0.8850"/>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</inertial>
    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
  </link>
  <link name="foot_L">
    <inertial><origin xyz="0.03626 0.00000 -0.05578" rpy="0 0 0"/><mass value="0.3350"/>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</inertial>
    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
  </link>
  <link name="hip_roll_bracket_R">
    <inertial><origin xyz="0.00200 -0.05580 0.00012" rpy="0 0 0"/><mass value="1.0710"/>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</inertial>
    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
  </link>
  <link name="hip_yaw_housing_R">
    <inertial><origin xyz="-0.03903 -0.00045 -0.08721" rpy="0 0 0"/><mass value="1.1970"/>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</inertial>
    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
  </link>
  <link name="thigh_R">
    <inertial><origin xyz="0.00000 -0.00733 -0.05914" rpy="0 0 0"/><mass value="1.1430"/>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</inertial>
    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
  </link>
  <link name="shank_R">
    <inertial><origin xyz="0.00000 0.02692 -0.14308" rpy="0 0 0"/><mass value="1.2320"/>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</inertial>
    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
  </link>
  <link name="ankle_block_R">
    <inertial><origin xyz="-0.09598 0.04366 -0.02592" rpy="0 0 0"/><mass value="0.8850"/>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</inertial>
    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
  </link>
  <link name="foot_R">
    <inertial><origin xyz="0.03626 0.00000 -0.05578" rpy="0 0 0"/><mass value="0.3350"/>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</inertial>
    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
  </link>
  <link name="shoulder_roll_bracket_L">
    <inertial><origin xyz="-0.00324 0.11689 0.00000" rpy="0 0 0"/><mass value="0.9210"/>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</inertial>
    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
  </link>
  <link name="upper_arm_yoke_L">
    <inertial><origin xyz="-0.03161 0.00000 -0.07125" rpy="0 0 0"/><mass value="0.5910"/>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</inertial>
    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
  </link>
  <link name="upper_arm_L">
    <inertial><origin xyz="0.00000 0.00156 -0.08327" rpy="0 0 0"/><mass value="0.6230"/>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</inertial>
    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
  </link>
  <link name="forearm_L">
    <inertial><origin xyz="0.00000 -0.03218 -0.12761" rpy="0 0 0"/><mass value="0.4530"/>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</inertial>
    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
  </link>
  <link name="hand_L">
    <inertial><origin xyz="0.00000 0.00000 -0.02950" rpy="0 0 0"/><mass value="0.1680"/>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</inertial>
    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
  </link>
  <link name="shoulder_roll_bracket_R">
    <inertial><origin xyz="-0.00324 -0.11689 0.00000" rpy="0 0 0"/><mass value="0.9210"/>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</inertial>
    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
  </link>
  <link name="upper_arm_yoke_R">
    <inertial><origin xyz="-0.03161 0.00000 -0.07125" rpy="0 0 0"/><mass value="0.5910"/>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</inertial>
    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
  </link>
  <link name="upper_arm_R">
    <inertial><origin xyz="0.00000 -0.00156 -0.08327" rpy="0 0 0"/><mass value="0.6230"/>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</inertial>
    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
  </link>
  <link name="forearm_R">
    <inertial><origin xyz="0.00000 0.03218 -0.12761" rpy="0 0 0"/><mass value="0.4530"/>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</inertial>
    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
  </link>
  <link name="hand_R">
    <inertial><origin xyz="0.00000 0.00000 -0.02950" rpy="0 0 0"/><mass value="0.1680"/>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</inertial>
    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
  </link>
  <joint name="waist" type="revolute">
    <parent link="pelvis"/><child link="torso"/>
    <origin xyz="0.00000 0.00000 0.59000" rpy="0 0 0"/><axis xyz="0 0 1"/>
    <limit lower="-1.5708" upper="1.5708" effort="60" velocity="20"/>
    <dynamics damping="0.2" friction="0.0"/>
  </joint>
  <joint name="hip_pitch_L" type="revolute">
    <parent link="pelvis"/><child link="hip_roll_bracket_L"/>
    <origin xyz="0.00000 0.07400 0.46000" rpy="0 0 0"/><axis xyz="0 1 0"/>
    <limit lower="-1.8326" upper="1.8326" effort="60" velocity="20"/>
    <dynamics damping="0.2" friction="0.0"/>
  </joint>
  <joint name="hip_roll_L" type="revolute">
    <parent link="hip_roll_bracket_L"/><child link="hip_yaw_housing_L"/>
    <origin xyz="0.04400 0.05800 0.00000" rpy="0 0 0"/><axis xyz="1 0 0"/>
    <limit lower="-0.2094" upper="1.8326" effort="60" velocity="20"/>
    <dynamics damping="0.2" friction="0.0"/>
  </joint>
  <joint name="hip_yaw_L" type="revolute">
    <parent link="hip_yaw_housing_L"/><child link="thigh_L"/>
    <origin xyz="-0.04400 0.00000 -0.13450" rpy="0 0 0"/><axis xyz="0 0 1"/>
    <limit lower="-1.5708" upper="1.5708" effort="60" velocity="20"/>
    <dynamics damping="0.2" friction="0.0"/>
  </joint>
  <joint name="knee_L" type="revolute">
    <parent link="thigh_L"/><child link="shank_L"/>
    <origin xyz="0.00000 0.04975 -0.06250" rpy="0 0 0"/><axis xyz="0 1 0"/>
    <limit lower="0.0000" upper="1.8326" effort="60" velocity="20"/>
    <dynamics damping="0.2" friction="0.0"/>
  </joint>
  <joint name="ankle_pitch_L" type="revolute">
    <parent link="shank_L"/><child link="ankle_block_L"/>
    <origin xyz="0.00000 0.01625 -0.16300" rpy="0 0 0"/><axis xyz="0 1 0"/>
    <limit lower="-0.8727" upper="0.8727" effort="60" velocity="20"/>
    <dynamics damping="0.2" friction="0.0"/>
  </joint>
  <joint name="ankle_roll_L" type="revolute">
    <parent link="ankle_block_L"/><child link="foot_L"/>
    <origin xyz="-0.06500 -0.05000 -0.03000" rpy="0 0 0"/><axis xyz="1 0 0"/>
    <limit lower="-0.5236" upper="0.5236" effort="36" velocity="20"/>
    <dynamics damping="0.2" friction="0.0"/>
  </joint>
  <joint name="hip_pitch_R" type="revolute">
    <parent link="pelvis"/><child link="hip_roll_bracket_R"/>
    <origin xyz="0.00000 -0.07400 0.46000" rpy="0 0 0"/><axis xyz="0 1 0"/>
    <limit lower="-1.8326" upper="1.8326" effort="60" velocity="20"/>
    <dynamics damping="0.2" friction="0.0"/>
  </joint>
  <joint name="hip_roll_R" type="revolute">
    <parent link="hip_roll_bracket_R"/><child link="hip_yaw_housing_R"/>
    <origin xyz="0.04400 -0.05800 0.00000" rpy="0 0 0"/><axis xyz="-1 0 0"/>
    <limit lower="-0.2094" upper="1.8326" effort="60" velocity="20"/>
    <dynamics damping="0.2" friction="0.0"/>
  </joint>
  <joint name="hip_yaw_R" type="revolute">
    <parent link="hip_yaw_housing_R"/><child link="thigh_R"/>
    <origin xyz="-0.04400 0.00000 -0.13450" rpy="0 0 0"/><axis xyz="0 0 -1"/>
    <limit lower="-1.5708" upper="1.5708" effort="60" velocity="20"/>
    <dynamics damping="0.2" friction="0.0"/>
  </joint>
  <joint name="knee_R" type="revolute">
    <parent link="thigh_R"/><child link="shank_R"/>
    <origin xyz="0.00000 -0.04975 -0.06250" rpy="0 0 0"/><axis xyz="0 1 0"/>
    <limit lower="0.0000" upper="1.8326" effort="60" velocity="20"/>
    <dynamics damping="0.2" friction="0.0"/>
  </joint>
  <joint name="ankle_pitch_R" type="revolute">
    <parent link="shank_R"/><child link="ankle_block_R"/>
    <origin xyz="0.00000 -0.01625 -0.16300" rpy="0 0 0"/><axis xyz="0 1 0"/>
    <limit lower="-0.8727" upper="0.8727" effort="60" velocity="20"/>
    <dynamics damping="0.2" friction="0.0"/>
  </joint>
  <joint name="ankle_roll_R" type="revolute">
    <parent link="ankle_block_R"/><child link="foot_R"/>
    <origin xyz="-0.06500 0.05000 -0.03000" rpy="0 0 0"/><axis xyz="-1 0 0"/>
    <limit lower="-0.5236" upper="0.5236" effort="36" velocity="20"/>
    <dynamics damping="0.2" friction="0.0"/>
  </joint>
  <joint name="shoulder_pitch_L" type="revolute">
    <parent link="torso"/><child link="shoulder_roll_bracket_L"/>
    <origin xyz="0.00000 0.09900 0.35000" rpy="0 0 0"/><axis xyz="0 1 0"/>
    <limit lower="-3.1416" upper="3.1416" effort="36" velocity="20"/>
    <dynamics damping="0.2" friction="0.0"/>
  </joint>
  <joint name="shoulder_roll_L" type="revolute">
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

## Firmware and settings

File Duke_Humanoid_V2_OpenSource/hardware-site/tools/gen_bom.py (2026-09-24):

"""Generate the six parts-list CSVs from the team's BOM spreadsheet.

    python tools/gen_bom.py [path/to/Duke_Humanoid_V2_BOM_WIP.xlsx] [path/to/tree.csv]

The team's spreadsheet ``reference/bom/Duke_Humanoid_V2_BOM_WIP.xlsx`` (one
sheet, 100 part lines) is THE source for every parts list on this site. It
replaces the two exported CSVs the retired ``gen_sheet1.py`` / ``gen_cnc.py``
read; where the two disagree, the spreadsheet wins.

    Category    rows          -> CSV
    Electronics E0-E20 (21)   -> actuators.csv (E1-E6), cables-connectors.csv
                                 (E9), electronics.csv (the rest)
    CNC         C0-C29 (30)   -> cnc-parts.csv
    3DP         P0-P39 (40)   -> printed-parts.csv
    Hardware    H0-H8  (9)    -> fasteners.csv

Every CSV carries the column contract of ``docs/data/README.md`` plus a last
column ``team_ref``: the spreadsheet's ``#`` value (``E3``, ``C21``, ``P20``,
``H1``) the row came from, blank for a row the spreadsheet has no line for.

What this script will not do
----------------------------
* **No invented price.** A blank or ``0`` unit cost becomes a *blank*
  ``unit_cost_usd`` and the note "Team BOM: no price yet", so the cost macros
  skip it and the pages print a red TODO. 39 of the 100 lines are unpriced: the
  30 unpriced 3DP lines and all 9 Hardware lines.
* **No invented mapping.** The CNC and 3DP rows of the spreadsheet carry no
  part IDs, so ``CNC_MAP`` / ``PRINTED_MAP`` below map them to the CAD-derived
  ``part_id``s the rest of the release keys on (``docs/files/<kind>/<part_id>_
  rev<NN>.*``, the viewer, ``part-properties.csv``). Every entry carries its
  evidence in a comment and, where the evidence is a group of parts rather
  than one part, the row itself says so and is marked UNVERIFIED.
* **No dropped CAD part.** A printed or machined part that is in the CAD but
  not in the spreadsheet is kept, unpriced, with the note "not in the team
  BOM". A spreadsheet row with no CAD match keeps its ``team_ref`` as its
  ``part_id`` and says "no CAD match yet".

What settles the mapping
------------------------
The team's exploded-view booklet ``reference/team/duke_humanoid_v2_hardware.pdf``
(15 pages, rendered as ``docs/assets/exploded/team/NN-*.webp``) labels the parts
of every assembly with the spreadsheet's own ids, so it is the evidence for
which CAD component each id is. ``BOOKLET`` below records, per id, the page(s)
that label it and what the label points at; ``OPEN`` records the ids the
booklet does **not** settle. Both are written to ``docs/data/team-map.csv``
together with the CAD counts, one row per spreadsheet line.

Run order: ``gen_bom.py`` (this file, writes all six CSVs and
``team-map.csv``, reads the newest ``cad/*/tree.csv``) then ``gen_cad_manifest.py``,
``gen_punchlist.py``, ``gen_image_manifest.py``. ``gen_printed.py`` is now the
``PRINTED`` mapping module (Fusion component -> ``part_id``) that this script,
``stage_cad_export.py``, ``build_viewer.py`` and ``gen_part_properties.py``
import; it no longer writes a CSV.
"""

from __future__ import annotations

import csv
import os
import re
import sys
from decimal import Decimal
from pathlib import Path

sys.path.insert(0, str(Path(__file__).resolve().parent))
from gen_printed import PRINTED, find_tree, load_tree, material_of, pick  # noqa: E402

SITE = Path(__file__).resolve().parent.parent
DATA = SITE / "docs" / "data"
SOURCE = Path(os.environ.get("BOM_SOURCE_DIR", SITE.parent / "reference" / "bom"))
XLSX = SOURCE / "Duke_Humanoid_V2_BOM_WIP.xlsx"

# The spreadsheet's own date: the file the team handed over on 2026-09-19.
PRICED_AS_OF = "2026-09-19"

COLS = ["subassembly", "class", "part_id", "description", "mpn", "vendor", "vendor_url",
        "alt_mpn", "alt_url", "qty_per_robot", "unit_cost_usd", "total_cost_usd",
        "material", "process", "tolerance_finish", "lead_time_days", "priced_as_of",
        "notes", "team_ref"]

NO_PRICE = "Team BOM: no price yet."
NOT_IN_BOM = "Not in the team BOM (Duke_Humanoid_V2_BOM_WIP.xlsx, 2026-09-19): no price and no quantity from it."
RS_ALT = ("SUPPLY RISK, no alternate published. A different actuator model changes the "
          "mounting interface, the shaft and the CAN configuration, so it is not a drop-in "
          "substitution.")

# Link domain -> vendor name. A domain that is not here keeps its host name and
# is reported, so no vendor is ever guessed silently.
VENDORS = {
    "mcmaster.com": "McMaster-Carr",
    "amazon.com": "Amazon",
    "aliexpress.us": "AliExpress",
    "digikey.com": "DigiKey",
    "aifitlab.com": "AiFitLab",
    "waveshare.com": "Waveshare",
    "robotshop.com": "RobotShop",
    "store.realsenseai.com": "RealSense Store",
    "zeeebattery.com": "Zeee",
    "epowerhobby.com": "ePowerHobby",
}

# --------------------------------------------------------------------------- #
# The team's exploded-view booklet: what each label points at.
#
# reference/team/duke_humanoid_v2_hardware.pdf, 15 pages, rendered as
# docs/assets/exploded/team/NN-<name>.webp. Page numbers below are the
# booklet's own (01-torso-frame = p.1 ... 15-whole-robot = p.15). Each entry
# describes what the label points at in the picture and nothing else: what is
# visible, never what is inferred from it. `—` means no page labels that id.
# --------------------------------------------------------------------------- #
BOOKLET: dict[str, tuple[str, str]] = {
    # --- electronics -------------------------------------------------------
    "E0": ("p.2", "the one large light box standing against the printed spine inside the torso"),
    "E1": ("p.9", "the small actuator at the wrist, one per arm"),
    "E2": ("p.9", "the three medium actuators of one arm (shoulder_3, elbow and wrist_1): "
                  "six positions for two arms, which is this line's count"),
    "E3": ("p.1, p.4, p.5", "three actuators in the torso plus four per leg (hip 1 and hip 2 on p.4, "
                            "hip 3 and ankle on p.5): eleven positions, which is this line's count"),
    "E4": ("p.5", "the wide actuator at the knee, one per leg"),
    "E5": ("p.9, p.14", "the short cylinder at the wrist (one per arm) and two per camera gimbal: "
                        "six positions, which is this line's count"),
    "E6": ("p.5, p.9", "the actuator at the ankle roll (one per leg) and at the shoulder (one per arm): "
                       "four positions, against this line's quantity of 2"),
    "E7": ("p.2", "two prismatic packs beside the torso"),
    "E8": ("—", "not labelled in the booklet"),
    "E9": ("—", "not labelled in the booklet"),
    "E10": ("p.13", "the green driver board above the gripper body, one per gripper"),
    "E11": ("—", "not labelled in the booklet"),
    "E12": ("p.13", "the grey converter on its plate beside the gripper body, one per gripper"),
    "E13": ("p.2", "six light boxes with a black connector, in two columns in the tray"),
    "E14": ("p.14", "the camera on the gimbal, one per column"),
    "E15": ("p.13", "the red and grey servo inside the gripper body, one per gripper"),
    "E16": ("p.2", "three port strips on the spine"),
    "E17": ("p.2", "the small module on the top plate of the torso"),
    "E18": ("p.2", "the stepped light block beside the torso"),
    "E19": ("p.2", "two small terminal blocks in the tray"),
    "E20": ("p.2", "two small blocks beside the torso"),
    # --- machined ----------------------------------------------------------
    "C0": ("p.1", "the rectangular plate closing the top of the torso, one off"),
    "C1": ("p.1", "the plate closing the bottom of the torso, with the large round bore, one off"),
    "C2": ("p.1", "the two tall side plates"),
    "C3": ("p.1", "four identical cross braces between the plates"),
    "C4": ("p.4, p.5", "the toothed ring in front of the H0 bearing on the output of the waist actuator "
                       "(p.4, the unlabelled actuator marked Body) and of the hip-1 (p.4) and hip-3 (p.5) "
                       "actuator of each leg: five positions, which is this line's count"),
    "C5": ("p.4, p.5, p.9", "the square coupler plate on the output of the same five RS03 joints (waist, "
                            "hip 1 and hip 3 of each leg) and of the shoulder-1 RS03 of each arm: seven "
                            "positions, which is this line's count"),
    "C6": ("p.4", "the ring bracket carrying the hip-1 actuator, one per leg"),
    "C7": ("p.4", "the flanged ring in front of the hip-2 actuator, one per leg"),
    "C8": ("p.4", "the forked bracket behind the hip-2 actuator, one per leg"),
    "C9": ("p.5", "the shaft arm on the driven side of the hip-3 joint, one per leg"),
    "C10": ("p.5", "the shaft arm on the support side of the hip-3 joint, one per leg"),
    "C11": ("p.5", "the ring bracket in front of the knee actuator, one per leg"),
    "C12": ("p.5", "the round cover behind the knee actuator, one per leg"),
    "C13": ("p.5", "the long shank arm on the driven side, one per leg"),
    "C14": ("p.5", "the long shank arm on the support side, one per leg"),
    "C15": ("p.5", "two small rings at the lower end of the shank arms, two per leg, which is this line's 4"),
    "C16": ("p.5", "the ring bracket at the ankle-pitch joint, one per leg"),
    "C17": ("p.5", "the forked retainer behind the ankle-pitch actuator, one per leg"),
    "E21": ("p.14", "the small angled connector between the camera and the arms, drawn with an unlabelled arrow"),
    "C18": ("p.5", "the ring on the RS06 ankle-roll actuator, one per leg"),
    "C19": ("p.5", "the short shaft arm on the driven side of the ankle roll, one per leg"),
    "C20": ("p.5", "the short shaft arm on the support side of the ankle roll, one per leg"),
    "C21": ("p.5", "the flat foot plate, one per leg"),
    "C22": ("p.9", "the ring plate in front of the shoulder-roll actuator, one per arm"),
    "C23": ("p.9", "the forked retainer behind the shoulder-roll actuator, one per arm"),
    "C24": ("p.9", "the flat shaft bracket at the shoulder, one per arm"),
    "C25": ("p.9", "the same rectangular bracket twice per arm, once at the shoulder and once at the "
                   "elbow, which is this line's name and its count of 4"),
    "C26": ("p.9", "the flat shaft bracket at the elbow, one per arm"),
    "C27": ("p.9", "the same round dished cover twice per arm, one in the shoulder joint stack and one "
                   "in the elbow joint stack, which is this line's name and its count of 4"),
    "C28": ("p.9", "the ring plate in front of the elbow actuator, one per arm"),
    "C29": ("p.9", "the forked retainer behind the elbow actuator, one per arm"),
    # --- printed -----------------------------------------------------------
    "P0": ("p.1", "the interior spine that stands inside the torso frame, one off"),
    "P1": ("p.3", "two identical window frames, one on the front face and one on the back"),
    "P2": ("p.3", "the perforated removable panel on one face of the torso"),
    "P3": ("p.3", "the perforated removable panel on the other face of the torso"),
    "P4": ("p.9", "the cone on the output of the first and of the third RS02 actuator of the arm "
                  "(shoulder_3 and wrist_1), two per arm"),
    "P5": ("p.9", "the square coupler block between the shoulder cone and the elbow actuator, one per arm"),
    "P6": ("p.9", "the barrel at the wrist roll, one per arm"),
    "P7": ("p.9", "the wrist housing of the arm drawn on p.9"),
    "P8": ("p.9", "the end-effector plate below the wrist, one per arm"),
    "P9": ("p.11", "the wrist housing of the mirrored arm: the same shape as P7 on p.9"),
    "P10": ("p.13", "the gripper body, one per gripper"),
    "P11": ("p.13", "the long slide arm with the rack teeth cut along it, two per gripper"),
    "P12": ("p.13", "the double-helix pinion on the servo, one per gripper"),
    "P13": ("p.13", "the curved ribbed finger pad, two per gripper"),
    "P14": ("p.13", "the flat tag holder, two per gripper"),
    "P15": ("p.13", "eight square tiles per gripper, at six label positions (two of them point at a pair): "
                    "sixteen for two grippers, against this line's 12"),
    "P16": ("p.14", "the wide tripod base at the foot of the column"),
    "P17": ("p.14", "the neck above the lower gimbal actuator"),
    "P18": ("p.14", "the thicker of the two gimbal arms: bent, ending in the bolt-circle pad that sits on "
                    "the actuator face"),
    "P19": ("p.14", "the thinner of the two gimbal arms: flat, ending in a plain disc beside the H5 bearing"),
    "P20": ("p.6", "one of the four curved vented covers around the hip-1 and hip-3 motors of one leg"),
    "P21": ("p.6", "one of the four curved vented covers around the hip-1 and hip-3 motors of one leg"),
    "P22": ("p.6", "one of the two curved covers around the hip-2 motor of one leg"),
    "P23": ("p.6", "one of the two curved covers around the hip-2 motor of one leg"),
    "P24": ("p.6", "one of the four curved vented covers around the hip-1 and hip-3 motors of one leg"),
    "P25": ("p.6", "one of the four curved vented covers around the hip-1 and hip-3 motors of one leg"),
    "P26": ("p.6", "one of the two curved covers around the knee motor of one leg"),
    "P27": ("p.6", "one of the two curved covers around the knee motor of one leg"),
    "P28": ("p.6", "two long flat straps with an eye at each end, one on each side of the shank of one leg, "
                   "which is this line's 4 over two legs"),
    "P29": ("p.6", "one of the two curved covers around the ankle-roll motor of one leg"),
    "P30": ("p.6", "one of the two curved covers around the ankle-roll motor of one leg"),
    "P31": ("p.6", "the small teardrop cap at the front of the foot, one per leg"),
    "P32": ("p.6", "the wedge sole under the foot plate, one per leg"),
    "P33": ("p.10", "one of the two curved covers around the shoulder-pitch motor of one arm"),
    "P34": ("p.10", "one of the two curved covers around the shoulder-pitch motor of one arm"),
    "P35": ("p.10", "two curved vented covers labelled P35 on one arm, both drawn at the shoulder end: "
                    "with P36's two they are the four halves of the two-piece roll cover, which is this "
                    "line's 4 over two arms"),
    "P36": ("p.10", "two curved vented covers labelled P36 on one arm, both drawn at the forearm end, "
                    "which is this line's 4 over two arms"),
    "P37": ("p.10", "one of the two curved covers around the elbow motor of one arm"),
    "P38": ("p.10", "one of the two curved covers around the elbow motor of one arm"),
    "P39": ("p.10", "four smooth flat covers per arm, two on the shoulder-roll shaft and two on the elbow "
                    "shaft: eight for two arms, which is this line's count"),
    # --- hardware ----------------------------------------------------------
    "H0": ("p.1, p.4, p.5", "the large bearing at the RS03 joints of the torso and of the legs"),
    "H1": ("p.5", "the bearing at the knee joint, one per leg"),
    "H2": ("p.5, p.9", "the bearings at the shank and at every arm joint"),
    "H3": ("p.5", "the bearings at the ankle, two per leg"),
    "H4": ("p.9", "the small bearing under the wrist housing, one per arm"),
    "H5": ("p.14", "the small bearing on the support side of the gimbal, one per column"),
    "H6": ("—", "screws are not labelled in the booklet"),
    "H7": ("—", "screws are not labelled in the booklet"),
    "H8": ("—", "screws are not labelled in the booklet"),
}

# What the booklet does NOT settle, one line per team BOM id. Everything else
# is `settled` in docs/data/team-map.csv.
OPEN: dict[str, str] = {
    "C25": "Unit price: the team BOM's 57.56 is exactly twice the retired machining quote's 28.78 for the "
           "same part. A drawing cannot price a part.",
    "P20": "Which of the four hip covers this line is, and whether Hip 1 has a cover of its own: the "
           "booklet draws four covers over two motors that do not all look alike, the 2026-09-19 CAD "
           "holds one two-piece design for all eight pieces, and neither names a line.",
    "P21": "Which of the four hip covers this line is (see P20).",
    "P22": "Which half of the hip-2 cover is A and which is B.",
    "P23": "Which half of the hip-2 cover is A and which is B.",
    "P24": "Which of the four hip covers this line is (see P20).",
    "P25": "Which of the four hip covers this line is (see P20).",
    "P26": "Which half of the knee cover is A and which is B.",
    "P27": "Which half of the knee cover is A and which is B.",
    "P29": "Which half of the ankle-roll cover is Top and which is Bot.",
    "P30": "Which half of the ankle-roll cover is Top and which is Bot.",
    "P33": "Which half of the shoulder-pitch cover is A and which is B.",
    "P34": "Which half of the shoulder-pitch cover is A and which is B.",
    "P35": "Which Fusion half is Front and which is Back; the booklet labels P35 twice at the shoulder "
           "end and P36 twice at the forearm end, so the two lines may split by joint rather than by half.",
    "P36": "Which Fusion half is Front and which is Back (see P35).",
    "P37": "Which half of the elbow cover is A and which is B.",
    "P38": "Which half of the elbow cover is A and which is B.",
    "H6": "Quantity: the team BOM gives none, and screws are not labelled in the booklet.",
    "H7": "Quantity: the team BOM gives none, and screws are not labelled in the booklet.",
    "H8": "Quantity: the team BOM gives none, and screws are not labelled in the booklet.",
}

# --------------------------------------------------------------------------- #
# purchased parts: Electronics (E0-E20) and Hardware (H0-H8)
#
# (team_ref, csv, part_id, subassembly, description, mpn, extra note). The
# part_ids of rows that were already published keep their IDs (gen_vendor_map.py
# and docs/assets/viewer/vendor-map.json key on them); new rows follow the same
# scheme. `description` is the curated English name where the item is unchanged,
# the spreadsheet's own text where it is new; the spreadsheet's text is in the
# notes of every row either way.
# --------------------------------------------------------------------------- #
ACT_FILE, EL_FILE, CAB_FILE, FAS_FILE = (
    "actuators.csv", "electronics.csv", "cables-connectors.csv", "fasteners.csv")

# Quantities the site publishes instead of the team sheet's, where the robot is known to
# differ from the spreadsheet. The line total follows the published quantity.
QTY_OVERRIDE: dict[str, str] = {
    "E6": "4",   # RS06: ankle_2 + shoulder_2, both sides (team sheet: 2)
}

# Printed-part quantities the site publishes instead of the Fusion occurrence count. The
# 2026-09-19 model carries the shank covers on the right leg only; the team BOM (P28, 4 off)
# and every other leg cover (both legs) say the robot has them on both legs.
PRINTED_QTY_OVERRIDE: dict[str, int] = {
    "3DP_legP09_shank_cover_a": 2,
    "3DP_legP10_shank_cover_b": 2,
}

# Small purchased parts the robot has that the team xlsx has no line for. Numbered on from
# the team's series (decided with the user, 2026-09-21) and listed as lab consumables: no
# price, no vendor, by decision ("鸡毛蒜皮的东西不标价"). (ref, csv, part_id, subassembly,
# description, mpn, qty, note)
SITE_PURCHASED: list[tuple[str, str, str, str, str, str, str, str]] = [
    ("E21", EL_FILE, "EL_USBC_ADAPTER", "electronics",
     "USB-C right-angle adapter, camera cable to the D436", "", "2",
     "Site-added line E21 (2026-09-21): the Fusion component `U-joint_type_C_adapter v3`, one per "
     "camera column, drawn on booklet p.14 with an unlabelled arrow. Not in the team xlsx yet: "
     "no price, no vendor."),
]
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

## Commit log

2026-09-24 Fully Open Humanoid v0.1 site
    [foh_v0_1.urdf]
2026-09-25 v0.2: joint kits on RobStride interfaces, self-collision audit, printable STLs, Pages workflow
    - Joint kits redesigned from the RobStride manuals: mount ring on the front lugs
    with an output support bearing pocket, printed coupler on the output boss with
    dowel locating, six through screws; support stubs for the inner plates
    - Straight arms on long shoulder brackets, pelvis narrowed to 264 mm hip
    spacing, torso frame moved to the corners; every clearance rechecked
    - tools/check_collisions.py: exact zero-pose audit, sampled pose audit and a
    per-joint range sweep; limits set where geometry binds
    - tools/build_parts.py: manifold3d CSG generator, 34 STLs + zip + manifest
    - Site: printing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
    [3DP_arm02_shoulder_bracket_v0_2.stl, 3DP_arm04_upper_arm_yoke_v0_2.stl, 3DP_arm06_upper_arm_v0_2.stl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]
2026-09-25 Fix printed-parts table script (variable shadowing)
2026-09-25 Coupler notes and kit screw lengths match the through-screw design
2026-09-25 MuJoCo physics check: the URDF stands, crouches and takes an 8 N·s push
    tools/sim_stand.py loads the generated URDF into MuJoCo with a floor, a
    floating base and torque-limited PD servos, then runs stand, crouch and
    4-12 N·s torso pushes. Results and frames are published on the software
    page with the walking-verification path. Crouch/reach presets now use
    negative hip pitch (forward flexion) so the audit poses match the sim.
2026-09-25 Sim frames in colour: URDF keeps visual materials, lit scene, collision geoms hidden
    The generated URDF now carries a <mujoco> compiler block (discardvisual
    off) and unique visual/collision geom names, so MuJoCo loads it with the
    part colours and no warnings. sim_stand.py adds a sky, checker floor and
    a shadow light and moves collision geoms to group 3. Results unchanged.
    [foh_v0_2.urdf]
2026-09-25 Catalog of open humanoids and a mix-and-match builder
    catalog.html scores 29 open humanoid, biped, upper-body and hand projects
    on nine OSHWA-style criteria with cost, size, DOF, actuators, licences and
    the sources each fact was read from; our design is listed on the same terms.
    builder.html mixes lower body, torso, arms, hands and head across projects,
    checks joint interfaces, actuator families and voltages, payload, scale and
    software, marks each check verified / unverified / adapter needed, and
    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
2026-09-25 Builder: live 3D view of the combination; catalog facts re-verified
    The builder now draws the selected modules in 3D as they change: one
    decimated GLB per module, composed by matching joint anchors (waist,
    shoulders, wrists, head mount). Geometry comes from our primitives, Duke
    V2's published viewer model, and the URDFs of Berkeley Humanoid Lite,
    LeRobot Humanoid, Open Duck Mini v2 and MEVITA; modules without public
    geometry get a labelled translucent box. tools/build_geometry.py generates
    assets/geom and assets/data/module_geom.json.
    Catalog: every entry re-checked against primary sources and stamped with
    the date. Corrections: K-Bot (20 DOF on RobStride 04/03/02/00), AgiBot X1
    (33 kg), Po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
2026-09-25 Catalog: form-factor column and eight bimanual, mobile, arm and legged entries
    Replaces the type field with a form taxonomy (humanoid, bimanual,
    bimanual + mobile, mobile manipulator, legged, arm, hand) shown as a
    column and a filter. Adds XLeRobot, LeKiwi, SO-ARM101, OpenArm v1,
    Mobile ALOHA, TidyBot++, Solo 12 and YOR with sources and licences
    checked against their repositories.
2026-09-25 Builder: parts from arms, hands, bases and quadrupeds; catalog +LEAP, +RUKA
    New modules with BOM lines and interfaces: SO-ARM101 and OpenArm v1 arm
    pairs, LEAP and RUKA hand pairs, LeKiwi and TidyBot++ wheeled bases, the
    Solo 12 quadruped, and the XLeRobot cart body and pan-tilt head. Lower
    and torso slots may be empty (a cart stands on its own wheels). New
    checks: licence (non-commercial or unstated donors), redundant hands on
    gripper-ended arms, wheeled bodies. 3D geometry added for SO-101, LEAP,
    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
2026-09-25 Builder view: scale donors to the legs, push parts into contact, mark joints
    Modules from other robots are scaled to the reference robot's height (the
    legs' catalog height, or leg height / 0.53 when unknown), shown in the
    legend and switchable. Cross-robot pairs are then adjusted from their
    bounding boxes: the torso onto the legs' top and centred, arms out of or
    into the torso side with a 5 mm gap and raised to the torso top, hands
    below the arm, the head onto and centred over the torso top. Same-design
    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
2026-10-02 v1 production design: BHL's extended configuration on RobStride, with its own page
    tools/build_v1.py generates the production design: the paper's adult-sized
    Fig. 5 layout (hip pitch/abduction/rotation stack on pelvis bars, one
    carbon-fibre tube per thigh, shank, upper arm and forearm between printed
    actuator cups, extrusion torso, dexterous hand) on RobStride RS04/03/06/02/05.
    RS04 interface dimensioned from the RS04 manual; laser-cut aluminium plates;
    polycarbonate covers; Amazing Hands. 1.64 m, 33 kg, 22 joints, core $6,325.
    Screw lengths are now computed from ring thickness, counterbore and thread
    depth with an engagement assertion (RS03/RS06 ring thickness corrected).
    Collision audit,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
2026-10-02 v1a aesthetic variant (WIP): cover shells over the production design, on its own page
    tools/build_v1a.py adds printed PLA shells to the v1 model: tapered thigh,
    shank, upper-arm and forearm covers, knee and shoulder discs, a torso shell
    with shoulder bezels replacing the polycarbonate panels, a pelvis cover, a
    rounded head with a visor and low shoes. Same mechanics; audit clean except
    the known straight-arm hip-roll coupling; MuJoCo pushes to 12 N·s pass.
    The shape pipeline gains cones, spheres and hollow boxes (build_data,
    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
2026-10-02 Styled design restarted from ROBOTIS' AI Sapiens K1 (v2, WIP); v1a cover shells retired
    tools/build_k1rs.py downloads the K1 description (hardware CERN-OHL-P-2.0),
    measures the housing around every joint from the published meshes (the STLs
    contain the actuators, so the farthest ray hit is the skin) and lists which
    RobStride fits each DYNAMIXEL-Q's envelope and which grows the shell, in a
    shape-first and a torque-first variant with cost and mass; aesthetic.html
    shows the K1 model with the actuator each joint gets and the swap table.
    The v1a page, generator, data, STLs and sim frames are removed (the cone,
    sphere and hollow-box primitives stay in the shape pipeline); the viewer,
    BOM and print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
2026-10-02 v2 skeleton: the AI Sapiens K1's joints and size built with RobStride kits, carbon tubes and printed blocks
    tools/build_v2.py places the v1 joint kits at the K1's joint positions: RS03
    at every hip, knee and ankle-pitch joint, RS06 at the waist, ankle roll and the
    two big shoulder joints, RS02 and RS05 down the arm; Ø30 carbon tubes in the
    thighs and shanks, printed blocks in the arms, a 2020 torso with a waist
    actuator hanging onto a printed waist plate. The forearm points forward at
    the zero pose, as the K1's does, because the hanging hand would meet the
    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
2026-10-03 v2 restarted as the extended Berkeley Humanoid Lite, built from BHL's own parts
    The styled design is now what the BHL paper draws in its Fig. 5: the robot
    brought to adult size with carbon-fibre tubes between its actuator modules,
    the hip reordered to pitch/abduction/rotation, a dexterous hand.
    tools/bhl_pieces.py cuts eleven printed parts out of BHL's published link
    meshes (CC BY-SA 4.0): the actuator modules removed, the arms cut where a
    tube takes over, the arm links straightened, the foot cradle raised 15 mm;
    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
2026-10-03 v2: torso cage narrowed to BHL's proportion, shoulder actuators outside it
    The 2020 cage is now 130 x 172 outside, as narrow as the mini PC allows
    (BHL's is 140 x 160); the packs, computer, boards and power parts stack
    vertically inside it, and the shoulder RS06s sit outside on a printed plate
    and beam bolted to the side uprights, as BHL's modules do. Audit clean,
    MuJoCo unchanged (stands, crouches, pushes to 10 N.s), 28 kg.
2026-10-03 v2: shoulders through the cage side as BHL's, arms hung 10 deg abducted at zero
    The shoulder RS06s now pass through the sides of the narrow cage between
    the corner uprights (an outside plate with the ring, an inside plate between
    the uprights), putting the shoulders 347 mm apart, BHL's 352. The hands clear
    the hip stack because the arms hang 10 deg abducted at the zero pose, as
    BHL's hang 15 deg: joints gained a fixed zero offset (zero_deg) that the
    URDF, the audit and the viewer apply. Audit clean, MuJoCo unchanged.
